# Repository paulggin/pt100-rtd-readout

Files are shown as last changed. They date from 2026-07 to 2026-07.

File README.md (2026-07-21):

# PT100 RTD Readout: Constant-Current 4-Wire Platinum Thermometry with a SPICE-Validated Front-End

**Author:** Paulino "Paul" Gin · BS Applied Physics + BA Mathematics, Boston College (Class of 2027)
**Stack:** KiCad 8 (schematic capture) · ngspice (SPICE) · Python (NumPy / Matplotlib)
**Repo:** [github.com/paulggin/pt100-rtd-readout](https://github.com/paulggin/pt100-rtd-readout)

---

## Overview

This project designs and simulates the readout electronics for a PT100 platinum resistance thermometer, which is the sensor for the warmer stages of a dilution refrigerator (50 K plate, still, vacuum can, anything from ~30 K to room temperature). The deliverable is a KiCad schematic and a SPICE-validated model of the full readout chain: a constant-current excitation source, a 4-wire (Kelvin) connection to the sensor, and a two-stage amplifier that maps the sensor's 0–100 °C range to a clean 0–3 V output, with the temperature recovered from that output through the inverse Callendar–Van Dusen relation.

The work includes five stages:

1. Size the circuit against self-heating and output-range targets: a 1.000 mA excitation current, an INA128 instrumentation amplifier at a gain of 10, and a difference amplifier at a gain of 7.87 that subtracts the 0 °C baseline.
2. Capture the schematic in KiCad 8 and a simulation-ready variant that solves in ngspice.
3. Sweep the modeled sensor resistance from 100 Ω to 138.5 Ω (0 → 100 °C) and confirm the readout output is linear and in range.
4. Recover temperature from the simulated output through the inverse Callendar–Van Dusen relation and quantify the accuracy.
5. Insert a lead resistance into the sensed loop and compare the 2-wire and 4-wire topologies directly.

## Background

**A PT100 is a platinum element with 100 Ω of resistance at 0 °C that rises by about 0.385 Ω/°C** along the IEC 60751 standard curve. For T ≥ 0 °C the Callendar–Van Dusen relation is

```
R(T) = R0 (1 + A·T + B·T²),   R0 = 100 Ω,  A = 3.9083e-3 /°C,  B = -5.775e-7 /°C²
```

which gives 138.5 Ω at 100 °C. Platinum is the standard choice for the warmer cryostat stages because its resistance-temperature curve is well characterized and nearly linear; colder stages (4 K and below) switch to RuOx or Cernox because platinum's sensitivity flattens out at low temperature. In simulation the PT100 is replaced by a fixed resistor set to R(T) for each temperature point, so sweeping the resistor is equivalent to sweeping the sensor.

**Why 4-wire , not 2-wire** PT100 usually sits at the end of a meter or more of cryostat wiring, and that wiring has its own resistance — easily 1–2 Ω round trip on thin, low-thermal-conduction wire. In a 2-wire hookup that lead resistance adds directly to the measured resistance and reads out as a false temperature shift of several °C. A 4-wire hookup carries the excitation current on one pair of wires and senses the voltage on a separate pair; because the sense pair feeds a high-impedance amplifier and carries no current, the lead resistance in the sense path drops nothing and the error cancels.

## Methods

### Signal chain

The readout is a **1.000 mA constant-current source, a 4-wire PT100, and a two-stage amplifier** that produces 0–3 V over 0–100 °C.

- **Excitation — improved Howland current pump, 1.000 mA.** The current is set by a 2.5 V reference (REF3025) and a precision resistor, I = V_ref / R_set. A Howland pump sources a defined current into a *grounded* load, which keeps the PT100 at ground and the instrumentation-amplifier common-mode near 0.1 V. Its usual weakness, finite output impedance degrading current regulation as the load changes, is irrelevant here because the load only moves 38.5 Ω across the full range; with 0.1 % matched resistors the current shifts ~40 nA (0.004 %) across 0–100 °C. At 1.000 mA the sensor dissipates 100–139 µW, far below the self-heating threshold, and produces 0.385 mV/°C at its terminals.

- **Stage 1 — INA128 instrumentation amplifier, gain 10.107.** The two sense leads feed the high-impedance INA128 inputs (the Kelvin condition), producing 1.00–1.39 V across the range. The gain is set by a single external resistor, G = 1 + 50 kΩ/R_G.

- **Stage 2 — difference amplifier, gain 7.87.** A four-resistor subtractor removes the 1.000 V (0 °C) baseline and applies the remaining gain, giving 0 → 3.0 V. Total signal gain is 10.107 × 7.87 ≈ 79.5, mapping the 38.5 mV sensor span to ~3 V.

- **Ratiometric baseline.** The 1.000 V subtraction voltage is derived from the same 2.5 V reference that sets the excitation current, so first-order reference drift cancels at the difference stage rather than reading out as a temperature error.

Full topology, sizing, error budget, BOM, and net list are in [`docs/DESIGN.md`](docs/DESIGN.md).

### SPICE modeling

**The amplifiers are represented by ideal macromodels for DC validation.** `INA128_IDEAL` is a fixed-gain (10.107) behavioral instrumentation amp referred to its REF pin; `OPAMP_IDEAL` is an open-loop VCVS op-amp. Every port is tied to ground through 1 GΩ so no node floats and the DC solve stays non-singular. This is a deliberate choice as the circuit's accuracy isn't limited by op-amp non-idealities (the input-referred offset budget is only ~0.04 °C) so ideal models are enough to validate what matters: the transfer function of the chain. Real-device offset, CMRR, and noise would be layered in with vendor subcircuits if the design targeted sub-0.01 °C accuracy.

**The sweep is a resistance sweep.** ngspice sweeps the PT100 resistor directly, `.dc RPT 100 138.5 0.385`, 101 points corresponding to 0–100 °C in ~1 °C steps. The 4-wire run senses at the PT100; the 2-wire run inserts a 2 Ω lead resistor into the excitation loop and senses on the electronics side of it, so the excitation current's drop across the lead is included in the measurement.

### Temperature recovery

`recovery_analysis.py` fits the readout transfer, then inverts each output voltage back to resistance and through the closed-form inverse Callendar–Van Dusen solution

```
T(R) = ( -A + sqrt(A² - 4B(1 - R/R0)) ) / (2B)
```

to recover temperature, and reports the residual for the ideal chain and for a quantized 12-bit ADC. `lead_study.py` applies the 4-wire calibration to both the 4-wire and 2-wire sweeps and reports the apparent-temperature error the lead resistance introduces.

## Results

**The readout output is linear in sensor resistance to the numerical floor.** A straight-line fit of V(Vout) against resistance gives R² = 1.00000000, with the output spanning 3.061 V over 0–100 °C — a 30.6 mV/°C slope at the ADC, which is a large, easily digitized signal.

**Temperature recovery is limited only by the ADC, not the analog chain.** Inverting the output through the Callendar–Van Dusen relation reproduces the input temperature to ~10⁻³ m°C for the ideal analog chain — the circuit itself contributes no error. With a realistic 12-bit ADC on a 3.3 V reference, recovery is ±0.013 °C, and the residual is pure quantization (a 16-bit ADC would push it to ~1 m°C). This is far below the accuracy class of the sensor itself.

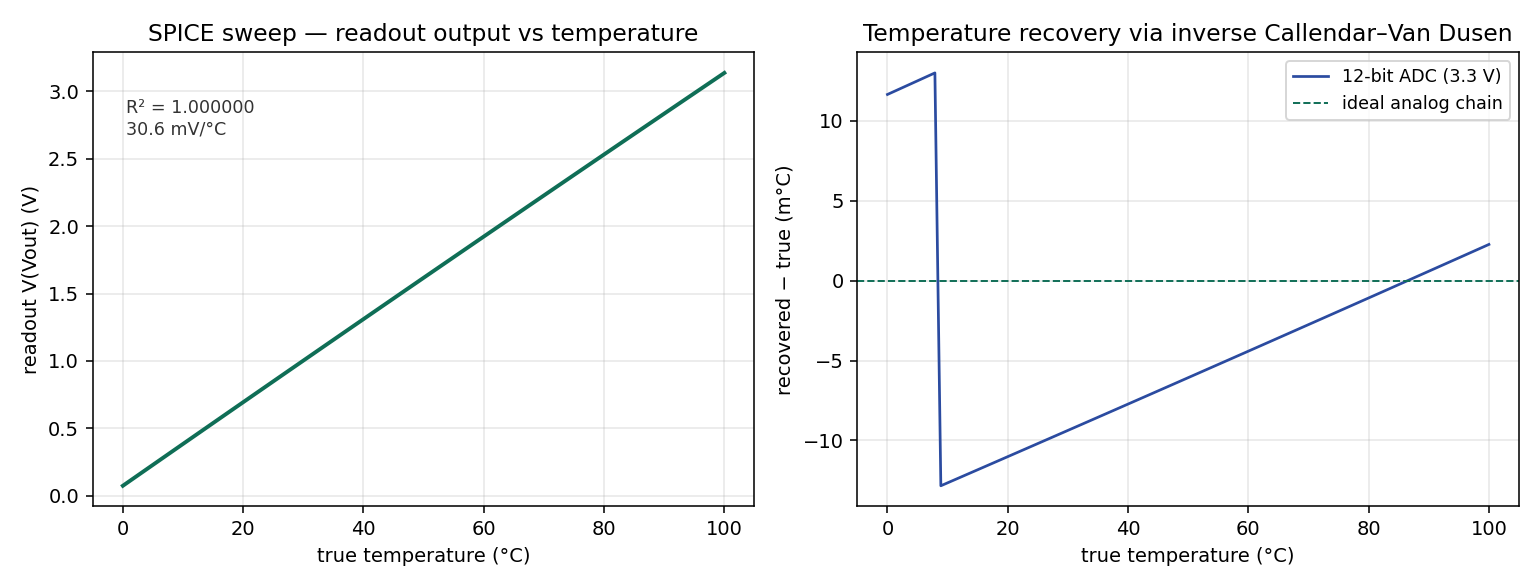
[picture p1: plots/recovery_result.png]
Temperature recovery


**Lead resistance costs +5.2 °C in 2-wire; 4-wire cancels it to 0.00 m°C.** With a 2 Ω lead resistance, the 2-wire hookup recovers a temperature high by +5.2 °C across the full range (5.12 °C at 0 °C, 5.28 °C at 100 °C — a flat offset, since the lead adds a fixed 2 Ω that looks like ~5 °C of extra platinum). The 4-wire connection cancels it to 0.00 m°C. Both curves are direct ngspice sweeps, and the +5.20 °C mean matches the `2·R_lead / (dR/dT)` arithmetic exactly.

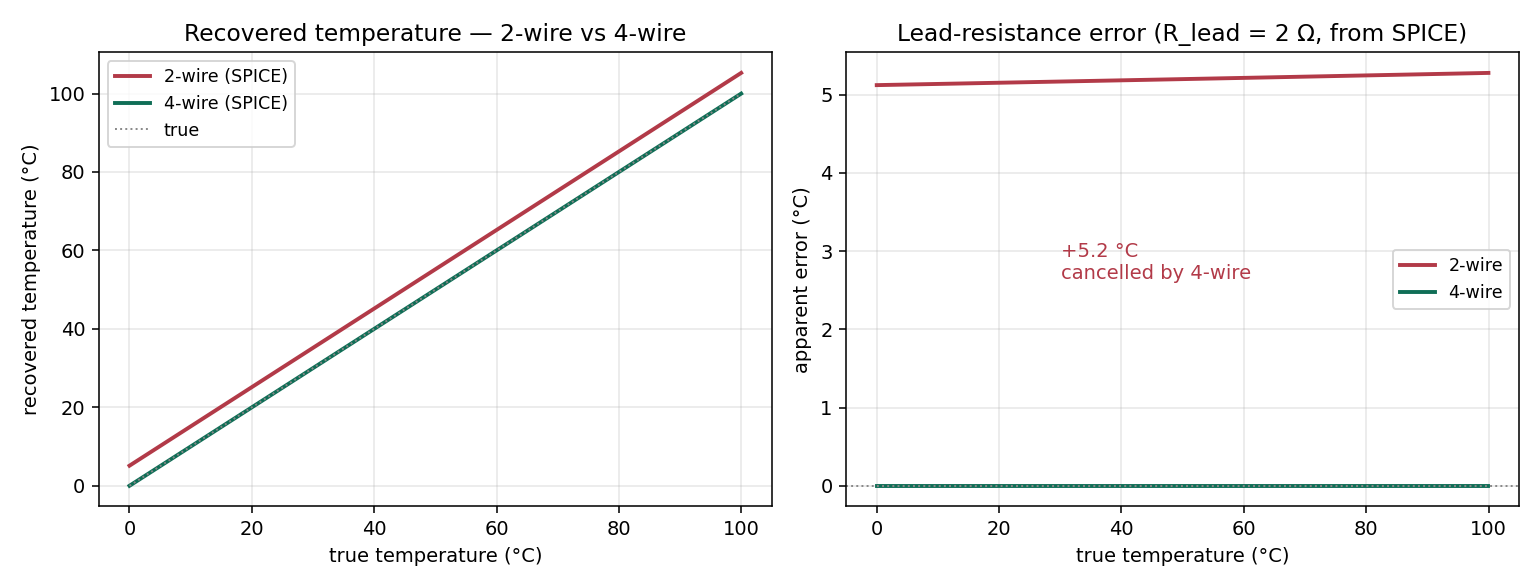
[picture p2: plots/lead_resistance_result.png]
Lead-resistance study


## Discussion

**What the ideal simulation validates.** The SPICE results confirm the transfer function of the readout: a 1.000 mA excitation into a 4-wire PT100 produces a linear, in-range output that inverts back to temperature with negligible loss, and a 4-wire connection removes a lead-resistance error that a 2-wire connection would read as several °C.

**What it does not.** A fabricated build's absolute accuracy would depend on real-device effects the ideal models skip like amplifier offset and drift, resistor tolerance and temperature coefficient, and reference drift (which the ratiometric baseline is designed to cancel to first order). Quantifying those is a Monte-Carlo pass over the validated transfer function, the next step before committing to hardware.

**Where the error actually comes from.** The amplifier's input-referred offset is ~0.04 °C, already below the sensor's own accuracy class, so a more detailed op-amp model wouldn't change the result. The error floor is set by the 2-wire vs. 4-wire topology and the ADC's bit depth instead.

## Repository layout

```
schematic/   buildable and simulation-ready schematic sheets (PDF)
spice/        ideal macromodels + 4-wire and 2-wire ngspice sweeps (CSV)
experiments/  temperature-recovery and lead-resistance analysis (Python)
plots/        generated figures
docs/         component-level design document
```

## Reproduce

```
pip install -r requirements.txt
python experiments/recovery_analysis.py     # -> plots/recovery_result.png
python experiments/lead_study.py            # -> plots/lead_resistance_result.png
```

The SPICE sweeps in `spice/` were produced in KiCad 8 / ngspice from the simulation-ready schematic; the Python reads those CSVs and regenerates the figures.

## Development Notes

Built with AI assistance (Claude) for boilerplate, syntax lookup, and debugging. Architecture, algorithm choices, and physics/math implementation are my own.
## References

IEC 60751 — Industrial platinum resistance thermometers (Callendar–Van Dusen coefficients).
J. Ekin, *Experimental Techniques for Low-Temperature Measurements* (Oxford, 2006), Ch. 5–6 — RTD thermometry, 4-wire sensing, lead-resistance error.
Texas Instruments INA128 datasheet; Texas Instruments REF3025 datasheet; Analog Devices LT1013 datasheet.

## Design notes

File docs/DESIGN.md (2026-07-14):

# Project 5 — PT100 RTD Readout: Circuit Design

Component-level design for the PT100 readout chain, finalized to the point of schematic capture. Every topology choice, component value, and gain target below is fixed; the remaining work is drawing it in KiCad and validating it in SPICE. All sizing numbers are reproduced by `experiments/sizing.py` (see the verification block at the end).

## Overview

The readout is a **1.000 mA constant-current excitation source, a 4-wire (Kelvin) PT100 connection, and a two-stage amplifier that maps the 0–100 °C range to a clean 0–3.00 V output**. The two stages are an INA128 instrumentation amplifier at a gain of 10, followed by a difference amplifier at a gain of 7.79 that subtracts the 0 °C baseline and trims the overall gain. Total signal gain is 77.9, which maps the 38.5 mV sensor span to 3.00 V.

The design is **ratiometric through a shared 2.5 V reference**: the same REF3025 that sets the excitation current also sets the baseline-subtraction voltage. Both the amplified PT100 signal and the subtracted baseline scale with the reference, so first-order reference drift cancels in the difference stage rather than reading out as a temperature error.

The PT100 is grounded on its low side and driven from a Howland current pump on its high side. This keeps the instrumentation-amplifier common-mode voltage near 0.1 V, well inside the INA128 input range on ±5 V rails, and avoids the near-rail common-mode problem that a high-side-grounded sensor would create.

## Sensor model (Callendar–Van Dusen)

For T ≥ 0 °C the platinum element follows R(T) = R₀(1 + A·T + B·T²) with R₀ = 100 Ω, A = 3.9083 × 10⁻³ °C⁻¹, B = −5.775 × 10⁻⁷ °C⁻² (IEC 60751). The design points the rest of the circuit is sized against:

| T (°C) | R (Ω) | V at 1.000 mA (mV) |
| :-- | --: | --: |
| 0 | 100.000 | 100.000 |
| 25 | 109.735 | 109.735 |
| 50 | 119.397 | 119.397 |
| 75 | 128.987 | 128.987 |
| 100 | 138.506 | 138.506 |

Sensitivity near 0 °C is 0.3908 Ω/°C, so at 1.000 mA the sensor produces 0.3908 mV/°C and a full-span swing of 38.505 mV. In SPICE the PT100 is replaced by a fixed resistor set to the R(T) value for each point in this table; sweeping the resistor stands in for sweeping temperature.

## Excitation current and self-heating

**I = 1.000 mA is the excitation current.** At that level the sensor dissipates I²R = 100.0 µW at 0 °C and 138.5 µW at 100 °C. A thin-film PT100 has a dissipation constant on the order of a few mW/°C in still air and far higher when clamped to a cold stage, so the self-heating error stays well under 0.1 °C and is negligible against the lead-resistance and amplifier error terms below. The same 1.000 mA sets the sensor-terminal sensitivity at 0.3908 mV/°C, which is the signal the front end has to resolve.

## Constant-current source: improved Howland current pump

**The excitation source is an improved Howland current pump set by the 2.5 V reference and a precision resistor, I = V_ref / R_set.** With R_set = 2.490 kΩ the current is 1.004 mA; with 2.500 kΩ it is exactly 1.000 mA. Absolute current accuracy is non-critical because the baseline subtraction shares the same reference, so 2.490 kΩ (a stock E96 value) is the recommended part and the residual 0.4 % current offset cancels in the difference stage.

I chose the Howland pump over a high-side op-amp-plus-pass-transistor source for one reason: it sources a defined current into a **grounded** load, which lets the PT100 sit at ground and keeps the instrumentation-amplifier common-mode near 0.1 V. The usual Howland weakness — finite output impedance degrading current regulation as the load changes — does not bite here because the load only moves 38.5 Ω across the full temperature range. With 0.1 % matched resistors the output impedance lands near 1 MΩ, so the current shifts by 38.5 nA (0.0039 % of 1 mA) across the entire 0–100 °C swing. That is two orders of magnitude below the amplifier error budget.

The matching of the four Howland resistors sets the output impedance, so they are specified as a 0.1 % matched network (or a single resistor-array package) and carry a low temperature coefficient. The op-amp is one half of an LT1013 dual precision op-amp. The LT1013 replaces the OPA2277 originally specified because KiCad's stock `Amplifier_Operational` library carries the LT1013 symbol directly; the two share the standard 8-pin dual pinout, so it is a drop-in swap. The offset penalty is immaterial here — the LT1013's ~150 µV offset, after the ×7.87 output-stage gain, contributes about 0.04 °C, well under the resistor-tolerance and lead-resistance terms — because the INA128 supplies the first ×10 and the sensor signal is a large 38.5 mV.

## Amplifier chain: INA128 stage + difference stage

**Stage 1 is an INA128 at a gain of 10**, reading the two PT100 sense leads on its high-impedance inputs so no current flows in the sense wires (the Kelvin condition). The INA128 gain law is G = 1 + 50 kΩ/R_G, so a gain of 10 needs R_G = 5.556 kΩ; the nearest E96 value, 5.49 kΩ, gives G = 10.107. Stage-1 output runs from 1.000 V at 0 °C to 1.385 V at 100 °C. Those voltages sit comfortably mid-range on ±5 V rails — the reason the front end uses a dual supply rather than a single +5 V rail, where the 1.000 V floor would crowd the INA128's minimum output.

**Stage 2 is a difference amplifier at a gain of 7.79** that subtracts a 1.000 V baseline and applies the remaining gain, producing 0 V at 0 °C and 3.00 V at 100 °C. The gain is set by the feedback ratio R_f/R_in; with R_in = 10.0 kΩ and R_f = 78.7 kΩ (E96) the gain is 7.87 and full-scale output is 3.03 V, which is the recommended pairing. Trimming R_f to 77.5 kΩ lands at exactly 2.984 V if a tighter full-scale target is wanted — final gain is set at this one resistor. The second op-amp is the other half of the OPA2277.

The 1.000 V subtraction node comes from the 2.5 V reference through a 0.400 divider ratio, buffered. Deriving it from the same REF3025 that sets the current is what makes the chain ratiometric: stage-1 baseline is G₁·I·R₀ = G₁·(V_ref/R_set)·R₀ and the subtracted voltage is k·V_ref, so both terms carry the V_ref factor and reference drift cancels to first order at the difference-stage input.

**Total signal gain is 10 × 7.79 = 77.9**, mapping the 38.505 mV sensor span to 3.00 V — the textbook ~78 the orientation called for, now pinned to real E96 parts.

## Why 4-wire: lead-resistance error budget

The 4-wire connection exists to cancel the resistance of the cryostat wiring between the warm electronics and the sensor. In a 2-wire hookup the measured resistance is R_PT100 + 2·R_lead, and that lead term reads out as a fixed positive temperature offset. The size of the error depends on wire gauge and run length:

| Wire | Run length (m) | 2-wire loop R (Ω) | Apparent error (°C) |
| :-- | --: | --: | --: |
| 28 AWG | 1.0 | 0.426 | +1.09 |
| 28 AWG | 2.0 | 0.852 | +2.18 |
| 32 AWG | 2.0 | 2.153 | +5.51 |

Cryostat wiring deliberately uses thin gauge to limit heat conducted down to the cold stages, which is exactly the case where the 2-wire error is worst: a 2 m run of 32 AWG copper adds 2.15 Ω of loop resistance, a +5.5 °C apparent shift, larger than the precision the sensor is otherwise capable of. The 4-wire connection removes it entirely because the sense leads carry no current — any drop across them is rejected by the instrumentation amplifier's high input impedance. The SPICE lead-resistance study models this directly by inserting series resistors into the excitation and sense lines and comparing the 2-wire and 4-wire topologies, and these are the numbers it should reproduce.

(The orientation's earlier estimate of 2.6–5.2 °C assumed a higher per-length resistance; recomputed against the standard 28 AWG value of 0.213 Ω/m, a 1–2 m run gives 1.1–2.2 °C, and the 5 °C case requires the thinner 32 AWG wire typical of cold-stage looms. The corrected numbers are in the table above.)

## Supply rails

The analog front end runs on **±5 V**. That gives the INA128 clean headroom around its 1.0–1.385 V stage-1 output and lets the difference stage swing to 0 V at the bottom of its range without fighting a single-supply floor. The 2.5 V reference and the 1.000 V subtraction node are both positive and derived from the +5 V rail through the REF3025. A single +5 V variant is possible with rail-to-rail parts but is not the recommended build, since it trades the INA128's well-characterized behavior for marginal output headroom.

## Bill of materials

| Ref | Part | Value / spec | Role |
| :-- | :-- | :-- | :-- |
| U1 | REF3025 | 2.500 V, ±0.05 %, 25 ppm/°C | Shared reference (current + baseline) |
| U2A | LT1013 (½) | dual precision op-amp | Howland current-pump amplifier |
| U2B | LT1013 (½) | dual precision op-amp | Stage-2 difference amplifier |
| U3A | LT1013 (½) | dual precision op-amp | Baseline-divider buffer (U3B spare) |
| U4 | INA128 | G = 1 + 50 kΩ/R_G | Stage-1 instrumentation amp |
| R_set | resistor | 2.490 kΩ, 0.1 %, low tempco | Sets I = V_ref/R_set ≈ 1.004 mA |
| R_H1–4 | matched network | 0.1 % matched, low tempco | Howland pump (sets output impedance) |
| R_G | resistor | 5.49 kΩ, 0.1 % | INA128 gain (G₁ = 10.11) |
| R_in | resistor | 10.0 kΩ, 0.1 % | Difference-stage input |
| R_f | resistor | 78.7 kΩ, 0.1 % | Difference-stage feedback (G₂ = 7.87) |
| R_d1, R_d2 | resistors | set 0.400 ratio | 1.000 V baseline divider from 2.5 V |
| RTD | PT100 (modeled) | 100 Ω → 138.5 Ω | Sensor; discrete resistor in SPICE |
| — | bypass caps | 100 nF per supply pin | Decoupling |

For the deferred physical build, the modeled PT100 becomes a real thin-film PT100 (~$8–12) and the SPICE resistor values map onto a precision resistor kit for ice-water / room / boiling-water calibration. Nothing in the schematic changes between the simulated and fabricated versions except swapping the resistor model for the sensor and connector.

## Net-level connection list (for KiCad capture)

Reference for drawing the schematic. Nets are named by function.

- **REF_2V5** — REF3025 output. Feeds the Howland current-set resistor R_set and the baseline divider R_d1/R_d2.
- **I_DRIVE+** — Howland pump output into the PT100 high side (force lead 1).
- **PT100_HI / PT100_LO** — the two sensor terminals. Force lead 2 returns PT100_LO to ground. Sense leads tap PT100_HI and PT100_LO and run to the INA128 inputs (these carry no current).
- **INA_IN+ / INA_IN−** — INA128 pins 2/3 from the sense leads. R_G across pins 1/8. REF pin (5) to ground.
- **STAGE1_OUT** — INA128 output (pin 6), 1.000–1.385 V. To difference-stage R_in.
- **VBASE_1V0** — buffered 1.000 V baseline from the divider. To the difference-stage reference input.
- **VOUT_0_3V** — difference-amplifier output, 0–3.00 V. ADC interface node.
- **+5V / −5V / GND** — supply rails; 100 nF decoupling at every device supply pin.

## What schematic capture and SPICE still have to confirm

1. **Stage-1 output stays in range.** SPICE sweep of R_PT100 from 100 Ω to 138.5 Ω should show STAGE1_OUT tracking 1.000–1.385 V and the Howland current holding 1.000 mA (±40 nA) across the swing.
2. **End-to-end mapping.** VOUT_0_3V should land at 0 V / 3.00 V at the endpoints and stay linear to within the resistor tolerances in between.
3. **Ratiometric cancellation.** Perturbing REF_2V5 should move STAGE1_OUT and VBASE_1V0 together, leaving VOUT_0_3V nearly unchanged — the first-order drift-cancellation claim.
4. **2-wire vs 4-wire.** Inserting the lead resistances from the table should leave the 4-wire output unchanged and shift the 2-wire output by the tabulated apparent error.

## References

IEC 60751 — Industrial platinum resistance thermometers (Callendar–Van Dusen coefficients).
J. Ekin, *Experimental Techniques for Low-Temperature Measurements* (Oxford, 2006), Ch. 5–6 — RTD thermometry, 4-wire sensing, lead-resistance error.
Texas Instruments INA128 datasheet; Analog Devices AD620 datasheet — instrumentation-amplifier gain and noise.
Texas Instruments REF3025 datasheet; Analog Devices LT1013 datasheet (op-amp, KiCad-library substitute for the OPA2277).

Finalized schematic sheet: `docs/pt100_readout_schematic.pdf`.
Project 4 (Cryostat Multi-Stage Thermal Model) — stage temperatures and wiring context for where this sensor sits in the fridge.

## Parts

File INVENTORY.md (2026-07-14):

# Inventory

## Schematic

| Path | Purpose |
|:--|:--|
| `schematic/pt100_readout_schematic.pdf` | Buildable schematic: improved Howland 1.000 mA current source, 4-wire PT100, INA128 instrumentation amp (×10), difference amplifier (×7.87) with a shared-reference baseline. Full BOM and net list in the sheet. |
| `schematic/pt100_sim_schematic.pdf` | Simulation-ready variant captured in KiCad 8: ideal current source, VDC rails, and ideal INA/op-amp macromodels, laid out to solve cleanly in ngspice. |
| `schematic/pt100_4wire.kicad_sch` | KiCad 8 schematic source, 4-wire configuration (ideal IDC excitation, INA128 + ideal OPAMP symbols, no lead resistor). Produced `spice/vout_sweep_4wire.csv`. |
| `schematic/pt100_2wire.kicad_sch` | KiCad 8 schematic source, 2-wire configuration (R5 = 2 Ω in the sensed loop, INA sensing on the current-source side of it). Produced `spice/vout_sweep_2wire.csv`. |

## SPICE

| Path | Purpose |
|:--|:--|
| `spice/ideal_models.lib` | Ideal macromodels used for DC validation. `INA128_IDEAL` is a fixed-gain (10.107) instrumentation amp referred to its REF pin; `OPAMP_IDEAL` is an open-loop VCVS op-amp. Every port is tied to ground through 1 GΩ so no node floats. |
| `spice/vout_sweep_4wire.csv` | ngspice `.dc` sweep of the sensor resistance 100 → 138.5 Ω (0 → 100 °C), 101 points. Columns: RPT (Ω), V(Vout) (V). 4-wire sensing. |
| `spice/vout_sweep_2wire.csv` | Same sweep with a 2 Ω lead resistance (R5) inside the sensed loop and the INA sensing on the electronics side of it. 2-wire sensing. |

## Source files

| Path | Purpose | LoC |
|:--|:--|:--|
| `experiments/recovery_analysis.py` | Loads the 4-wire sweep, fits the readout transfer, inverts each output through the Callendar–Van Dusen relation to recover temperature, and quantifies the residual for the ideal analog chain and for a 12-bit ADC. Generates `plots/recovery_result.png`. | ~30 |
| `experiments/lead_study.py` | Compares the 4-wire and 2-wire SPICE sweeps under a common calibration and reports the apparent-temperature error introduced by the lead resistance. Generates `plots/lead_resistance_result.png`. | ~35 |

## Figures

| Path | Generated by | Description |
|:--|:--|:--|
| `plots/recovery_result.png` | `recovery_analysis.py` | Left: readout output vs temperature (R² = 1.000000, 30.6 mV/°C). Right: temperature-recovery error via inverse Callendar–Van Dusen, ideal chain vs 12-bit ADC. |
| `plots/lead_resistance_result.png` | `lead_study.py` | Left: recovered temperature, 2-wire vs 4-wire. Right: apparent error vs temperature — 2-wire reads +5.2 °C, 4-wire cancels to 0. |

## Documentation

| Path | Purpose |
|:--|:--|
| `docs/DESIGN.md` | Component-level design: topology decisions, current-source and gain sizing, error budget, BOM, and the net-level connection list for schematic capture. |

## KiCad source

The simulation schematic source is committed as two KiCad 8 sheets — `schematic/pt100_4wire.kicad_sch` and `schematic/pt100_2wire.kicad_sch` — one per wiring configuration. They open standalone in the schematic editor; the ideal-model assignments reference `spice/ideal_models.lib`. The two PDFs are exact renders of the buildable and simulation-ready sheets.

## Reproducibility

Python 3.10+, `pip install -r requirements.txt`. From the repository root:

```
python experiments/recovery_analysis.py
python experiments/lead_study.py
```

Both scripts read the committed CSVs in `spice/` and write their figures to `plots/`. The SPICE sweeps themselves were produced in KiCad 8 / ngspice from the simulation-ready schematic with `.dc RPT 100 138.5 0.385`.

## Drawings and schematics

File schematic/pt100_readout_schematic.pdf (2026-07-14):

# PT100 four-wire RTD readout

## bill of materials

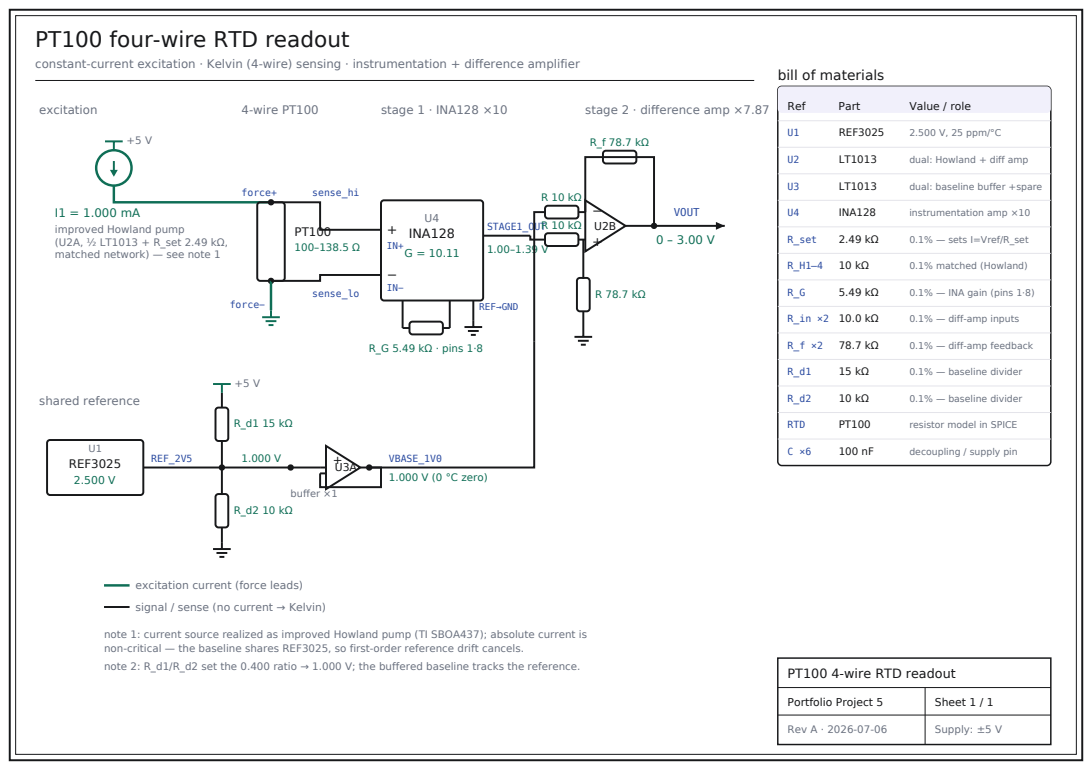
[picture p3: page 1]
excitation; 4-wire PT100; force+; sense_hi; force−; sense_lo; stage 1 · INA128 ×10; INA128; R_G 5.49 kΩ · pins 1·8; REF→GND; STAGE1_OUT; VOUT; shared reference; REF3025; REF_2V5; buffer ×1; VBASE_1V0; 1.000 V (0 °C zero); Ref; Part; Value / role; 2.500 V, 25 ppm/°C; dual: Howland + diff amp; dual: baseline buffer +spare; instrumentation amp ×10; R_set; 0.1% — sets I=Vref/R_set; 0.1% matched (Howland); 0.1% — INA gain (pins 1·8); 0.1% — diff-amp inputs; 0.1% — diff-amp feedback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

constant-current excitation · Kelvin (4-wire) sensing · instrumentation + difference amplifier

stage 2 · difference amp ×7.87

improved Howland pump
(U2A, ½ LT1013 + R_set 2.49 kΩ,
matched network) — see note 1

excitation current (force leads)
signal / sense (no current → Kelvin)

note 1: current source realized as improved Howland pump (TI SBOA437); absolute current is
non-critical — the baseline shares REF3025, so first-order reference drift cancels.
note 2: R_d1/R_d2 set the 0.400 ratio → 1.000 V; the buffered baseline tracks the reference.

PT100 4-wire RTD readout

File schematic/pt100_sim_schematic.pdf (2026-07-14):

# PT100 readout — simulation-ready

## simulation setup

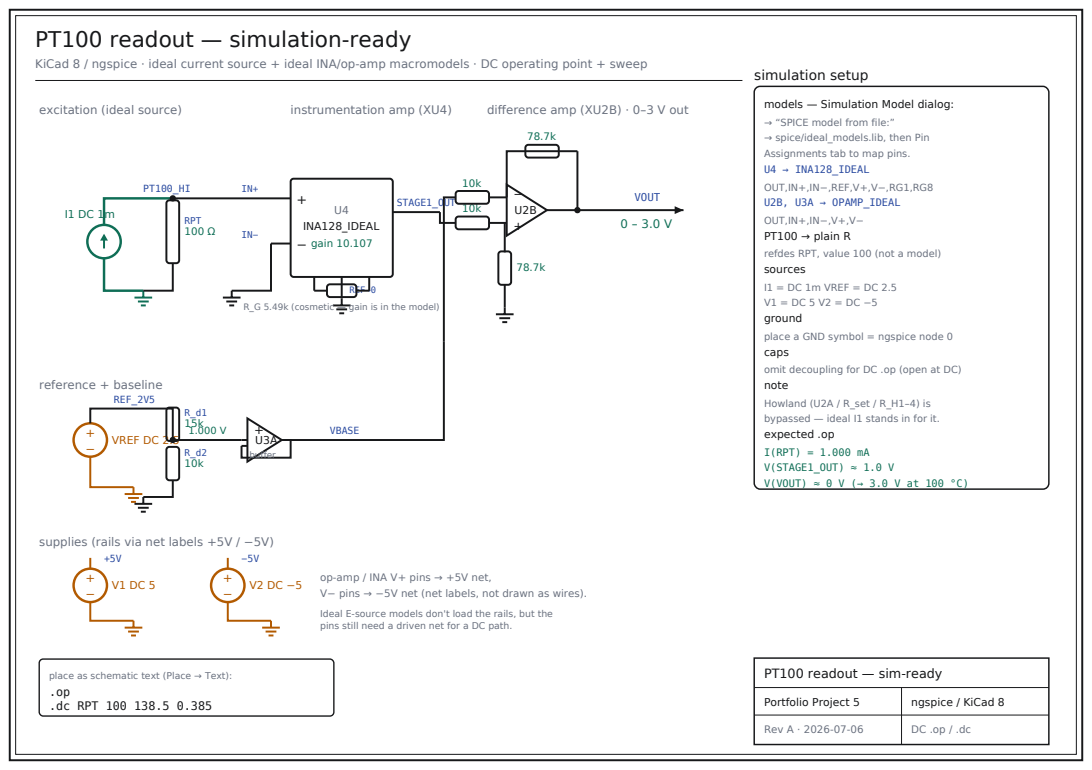
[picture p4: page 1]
RPT; instrumentation amp (XU4); U4 INA128_IDEAL; gain 10.107; REF→0; STAGE1_OUT; VOUT; reference + baseline; VREF DC 2.5; REF_2V5; buffer; VBASE; Portfolio Project 5; ngspice / KiCad 8; Rev A · 2026-07-06

KiCad 8 / ngspice · ideal current source + ideal INA/op-amp macromodels · DC operating point + sweep

excitation (ideal source)

difference amp (XU2B) · 0–3 V out

models — Simulation Model dialog:
→ “SPICE model from file:”
→ spice/ideal_models.lib, then Pin
Assignments tab to map pins.
U4 → INA128_IDEAL
OUT,IN+,IN−,REF,V+,V−,RG1,RG8
U2B, U3A → OPAMP_IDEAL
OUT,IN+,IN−,V+,V−
PT100 → plain R
refdes RPT, value 100 (not a model)
sources
I1 = DC 1m VREF = DC 2.5
ground
place a GND symbol = ngspice node 0
caps
omit decoupling for DC .op (open at DC)
note
Howland (U2A / R_set / R_H1–4) is
bypassed — ideal I1 stands in for it.
expected .op
I(RPT) = 1.000 mA
V(STAGE1_OUT) ≈ 1.0 V
V(VOUT) ≈ 0 V (→ 3.0 V at 100 °C)

R_G 5.49k (cosmetic — gain is in the model)

supplies (rails via net labels +5V / −5V)

op-amp / INA V+ pins → +5V net,
V− pins → −5V net (net labels, not drawn as wires).
Ideal E-source models don't load the rails, but the
pins still need a driven net for a DC path.

place as schematic text (Place → Text):
.dc RPT 100 138.5 0.385

PT100 readout — sim-ready

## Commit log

2026-07-14 PT100 RTD readout: SPICE-validated 4-wire front-end (schematic, sims, analysis)
    [vout_sweep_2wire.csv, vout_sweep_4wire.csv]
2026-07-14 Add KiCad schematic source and update inventory
    [pt100.01.kicad_sch]
2026-07-14 Add 4-wire and 2-wire KiCad schematic sources
    [pt100_2wire.kicad_sch, pt100_4wire.kicad_sch]
